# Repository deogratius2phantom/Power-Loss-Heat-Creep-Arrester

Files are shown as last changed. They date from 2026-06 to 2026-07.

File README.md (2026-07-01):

# Power Loss Heat Creep Arrester

A KiCad PCB design for a timer circuit that provides **24 V backup power to a 3D printer hotend fan** in the event of a power loss during printing. This prevents heat creep — the condition where residual heat travels up into the heatsink passage, causing filament to swell, clog, or jam.

---

## Overview

When a 3D printer loses power mid-print, the hotend heater turns off but residual heat remains in the heater block. Without the cooling fan running, this heat can creep up the cold zone, softening and swelling the filament inside the heatsink passage. The result is a jam that requires manual disassembly to clear.

This circuit detects the power loss event and uses a backup energy source (e.g. a capacitor bank or small battery) to keep the hotend fan spinning for a timed period — long enough for the heat to dissipate safely.

---

## Features

- Detects main power loss and triggers a timed backup fan drive
- Designed to supply 24 V to a standard 3D printer part-cooling or hotend fan
- Powered by a **Nokia BL-5C 3.7 V Li-ion battery** — widely available, compact, and plug-in replaceable
- Compact PCB footprint suitable for mounting inside a printer enclosure
- Fully open hardware (CC0 1.0 Universal licence)

---

## Board Preview

**Front (component side)**
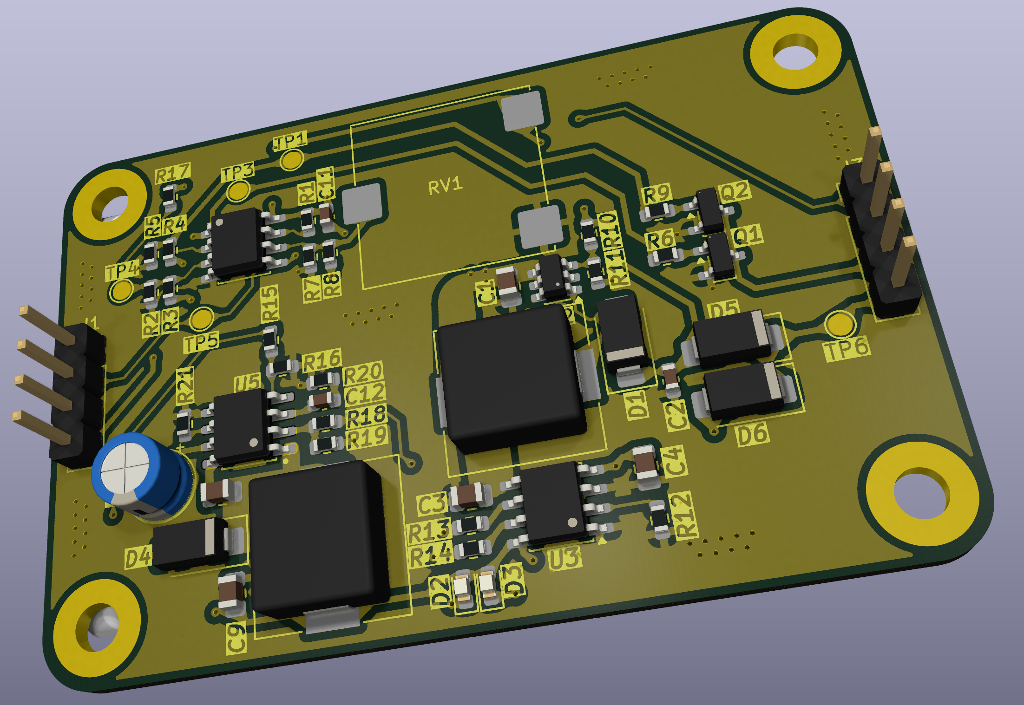
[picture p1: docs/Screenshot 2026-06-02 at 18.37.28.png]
Board Front


**Back — rev_1.0 silkscreen**
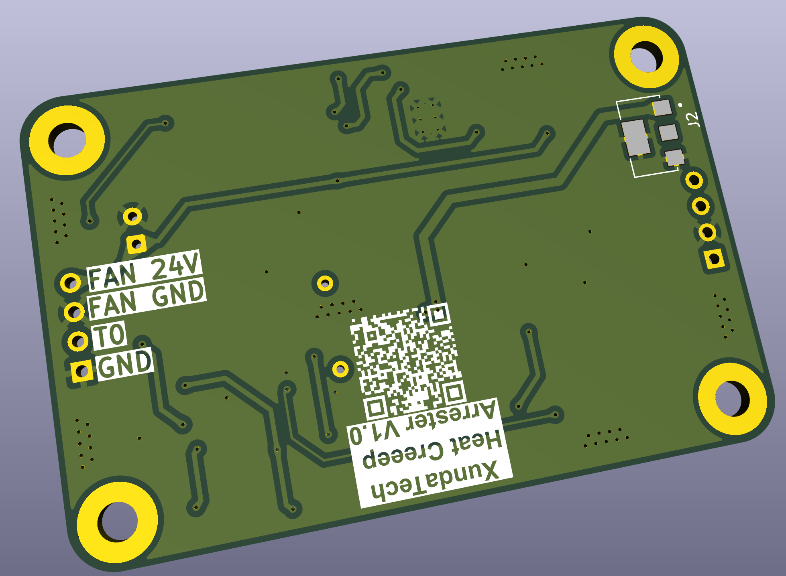
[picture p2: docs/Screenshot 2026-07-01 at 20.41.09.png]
Board Back rev_1.0


The back silkscreen includes:
- **XundaTech / Heat Creep Arrester V1.0** — product branding
- **QR code** — scan to open this GitHub repository directly from the physical board
- **Connector pinout labels** (`FAN 24V`, `FAN GND`, `TO`, `GND`) — printed next to J3 for field assembly without needing a datasheet

📄 Full schematic & layout documentation: [PowerLossHeatCreepArrester.pdf](docs/PowerLossHeatCreepArrester.pdf)

---

## Repository Structure

```
Power-Loss-Heat-Creep-Arrester/
├── PowerLossHeatCreepArrester_v1.0/                      # KiCad v1.0 project (main design)
│   ├── PowerLossHeatCreepArrester_v1.0.kicad_pro         # KiCad project file
│   ├── PowerLossHeatCreepArrester_v1.0.kicad_sch         # Schematic
│   ├── PowerLossHeatCreepArrester_v1.0.kicad_pcb         # PCB layout
│   ├── board_v1.step                                     # 3D board export (v1)
│   ├── board_v11.step                                    # 3D board export (v11)
│   ├── .step                                             # Additional 3D export
│   ├── fabrication-toolkit-options.json                  # KiCad fabrication toolkit config
│   ├── bom/                                              # Bill of Materials & assembly aids
│   │   └── manual_assembly_ibom.html                    # Interactive BOM for manual assembly
│   └── production/                                       # Ready-to-order production files
│       ├── PowerLossHeatCreepArrester_v1.0.zip           # Gerber bundle for PCB fab
│       ├── bom.csv                                       # Bill of Materials
│       ├── designators.csv                               # Component designators
│       ├── netlist.ipc                                   # IPC netlist
│       └── positions.csv                                 # Pick-and-place positions
├── libraries/
│   └── PowerLossHeatCreepArrester.kicad_sym              # Custom schematic symbols
├── footprints/
│   └── PowerLossHeatCreepArrester.pretty/                # Custom PCB footprints
├── fabrication/
│   ├── gerbers/                                          # Gerber files for PCB manufacture
│   └── bom/                                             # Bill of Materials exports
├── docs/                                                 # Documentation & board images
│   ├── PowerLossHeatCreepArrester.pdf                   # Full schematic & layout PDF
│   ├── Screenshot 2026-06-02 at 18.37.28.png            # Board front view
│   └── Screenshot 2026-06-02 at 18.37.43.png            # Board back view
├── Heat Creep Arrester.pdf                               # Project overview document
├── .gitignore
├── LICENSE
└── README.md
```

---

## Getting Started

### Prerequisites

- [KiCad 7 or later](https://www.kicad.org/download/) (the project files use the KiCad 6+ S-expression format)

### Opening the Project

1. Clone or download this repository.
2. Open KiCad and select **File → Open Project**.
3. Navigate to `PowerLossHeatCreepArrester_v1.0/` and open `PowerLossHeatCreepArrester_v1.0.kicad_pro`.
4. The schematic (`*.kicad_sch`) and PCB layout (`*.kicad_pcb`) will be available from the KiCad project manager.

### Generating Fabrication Files

### Interactive BOM (Manual Assembly)

Open the interactive BOM directly in your browser — no setup needed:

**🔗 [View Interactive BOM online](https://htmlpreview.github.io/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)**

Or open the file locally: `PowerLossHeatCreepArrester_v1.0/bom/manual_assembly_ibom.html`

It provides an interactive board view where you can click each component to highlight its placement — ideal for hand-soldering.

### Production Files

Ready-to-order files are in `PowerLossHeatCreepArrester_v1.0/production/`:

| File | Description |
|---|---|
| `PowerLossHeatCreepArrester_v1.0.zip` | Gerber bundle — upload directly to your PCB fab |
| `bom.csv` | Bill of Materials |
| `designators.csv` | Component designator mapping |
| `netlist.ipc` | IPC-D-356 netlist |
| `positions.csv` | Pick-and-place positions for SMT assembly |

To regenerate from source in KiCad PCB Editor (`pcbnew`):

1. Go to **File → Fabrication Outputs → Gerbers** → output to `fabrication/gerbers/`.
2. Generate the drill file via **File → Fabrication Outputs → Drill Files**.
3. Export the BOM via **File → Fabrication Outputs → BOM** → output to `fabrication/bom/`.

---

## Design Notes

| Parameter | Value |
|---|---|
| Supply voltage | 24 V |
| Target load | Hotend / part-cooling fan |
| Fan activation | Only when hotend > 50 °C (adjustable via RV1) |
| Temperature sensing | Independent thermistor circuit (U4) — separate from printer NTC |
| PCB layers | 2 |
| Board thickness | 1.6 mm |
| Solder mask clearance | 0.005 mm |

---

## Revision History

### rev_1.0 (current branch)

Key changes from initial commit:

- **Independent temperature monitoring (U4 added):** A dedicated temperature sensing IC with its own thermistor was added after determining it is not feasible to share the printer's NTC across both the printer control board and this backup supply board without a carefully designed 3.3 V interface. U4 provides a clean, isolated temperature signal to LM393 comparator 2.
- **Comparator voltage divider recalculated:** R15 `210k → 52.3k`, R16 `40.2k → 10k` — revised to correctly set the 24 V power-loss detection threshold.
- **Hysteresis / reference network updated:** R21 `200k → 100k`, plus two comparator reference resistors adjusted (`10k → 47k` and `10k → 910k`) to match the new divider ratios.
- **GND symbol rerouted and thermistor label repositioned** on the schematic for clarity.
- **Net label typo fixed:** `indipendent_3d printer fan control input` → `independent_3d printer fan control input`.
- **PCB layout updated:** U4 placed at (138.51, 88.06), net assignments updated to match schematic changes, solder mask clearance set to 0.005 mm.
- **Back silkscreen additions:**
  - Product branding: `XundaTech / Heat Creep Arrester V1.0`
  - QR code linking to this GitHub repository (centre-back)
  - Connector pinout labels beside J3: `FAN 24V`, `FAN GND`, `TO`, `GND`

---

## Documentation

Full project documentation is in the [**GitHub Wiki**](https://github.com/deogratius2phantom/Power-Loss-Heat-Creep-Arrester/wiki):

| Wiki Page | Contents |
|---|---|
| [Design Rationale](https://github.com/deogratius2phantom/Power-Loss-Heat-Creep-Arrester/wiki/Design-Rationale) | Why BL-5C, MT3608, TP4056, LM393 were chosen |
| [Circuit Theory](https://github.com/deogratius2phantom/Power-Loss-Heat-Creep-Arrester/wiki/Circuit-Theory) | How each circuit block works |
| [Bill of Materials & Sourcing](https://github.com/deogratius2phantom/Power-Loss-Heat-Creep-Arrester/wiki/Bill-of-Materials-and-Sourcing) | Full component list with supplier links |
| [Assembly Guide](https://github.com/deogratius2phantom/Power-Loss-Heat-Creep-Arrester/wiki/Assembly-Guide) | Step-by-step soldering instructions |
| [Testing & Calibration](https://github.com/deogratius2phantom/Power-Loss-Heat-Creep-Arrester/wiki/Testing-and-Calibration) | Verifying and tuning the circuit |
| [Troubleshooting](https://github.com/deogratius2phantom/Power-Loss-Heat-Creep-Arrester/wiki/Troubleshooting) | Common issues and fixes |
| [Version History](https://github.com/deogratius2phantom/Power-Loss-Heat-Creep-Arrester/wiki/Version-History) | Board revision log |

---

## Contributing

Contributions are welcome. See the [Contributing wiki page](https://github.com/deogratius2phantom/Power-Loss-Heat-Creep-Arrester/wiki/Contributing) for the full workflow. Please open an issue to discuss changes before submitting a pull request.

---

## Licence

This project is released into the public domain under the [CC0 1.0 Universal](LICENSE) licence. You are free to use, modify, and distribute this design without restriction.

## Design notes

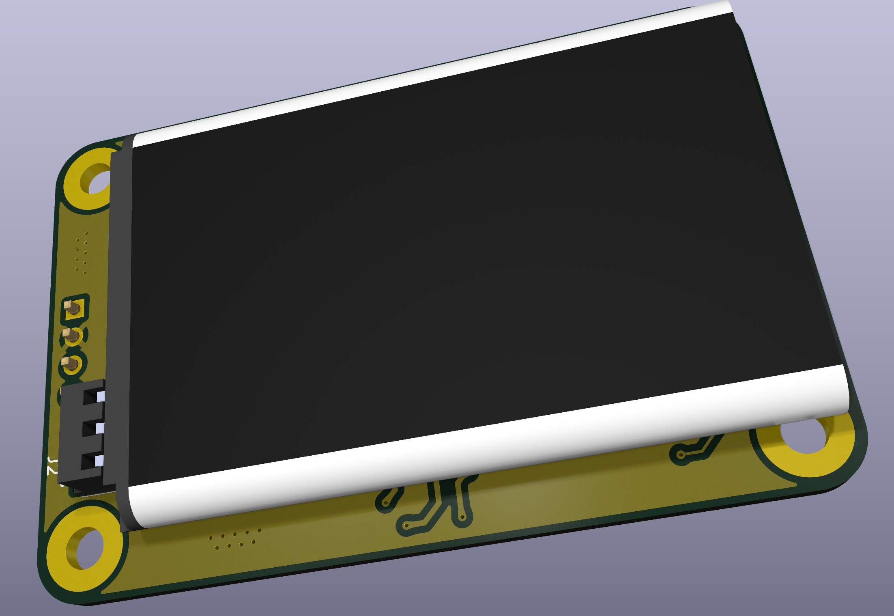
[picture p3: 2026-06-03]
docs/Screenshot 2026-06-02 at 18.37.43.png

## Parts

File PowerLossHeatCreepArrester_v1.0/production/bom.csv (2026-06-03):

Designator | Footprint | Quantity | Value | LCSC Part #
C1, C9 | 0805 | 2 | 22uF
C11, C2 | 0603 | 2 | 22uF
C12 | 0603 | 1 | 150pF
C3, C4 | 0805 | 2 | 10uF
C5 | 0805 | 1 | 1uF
C7 | CP_Radial_D5.0mm_P2.50mm | 1 | 100uF
D1, D4, D5, D6 | D_SMA | 4 | D
D2, D3 | 0603 | 2 | LED
J1 | PinHeader_1x04_P2.54mm_Vertical | 1 | Conn_01x04_Socket
J2 | AMPHENOL_BC3550Y0302A | 1 | BC3550Y0302A
J3 | PinHeader_1x04_P2.54mm_Vertical | 1 | Conn_01x04_Pin
L1, L2 | L_10.4x10.4_H4.8 | 2 | 22uH
Q1, Q2 | SOT-23 | 2 | BSS138
R1, R10, R11, R2, R3, R4, R7, R8 | 0603 | 8 | 10k
R12 | 0603 | 1 | 1.4k
R13, R14, R6, R9 | 0603 | 4 | 1k
R15 | 0603 | 1 | 210k
R16 | 0603 | 1 | 40.2k
R17 | 0603 | 1 | 1M
R18, R20 | 0603 | 2 | 100k
R19 | 0603 | 1 | 24.9k
R21 | 0603 | 1 | 200k
R5 | 0603 | 1 | 4.7k
RV1 | Potentiometer_ACP_CA14-VSMD_Vertical | 1 | 10K
TP1, TP3, TP4, TP5, TP6 | TestPoint_Pad_D1.5mm | 5 | TestPoint_Alt
U1 | SOIC-8_3.9x4.9mm_P1.27mm | 1 | LM393
U2 | SOT-23-6 | 1 | MT3608
U3 | SOIC-8-1EP_3.9x4.9mm_P1.27mm_EP2.41x3.3mm_ThermalVias | 1 | TP4056-42-ESOP8
U5 | SOIC127P600X170-9N | 1 | MP1584EN

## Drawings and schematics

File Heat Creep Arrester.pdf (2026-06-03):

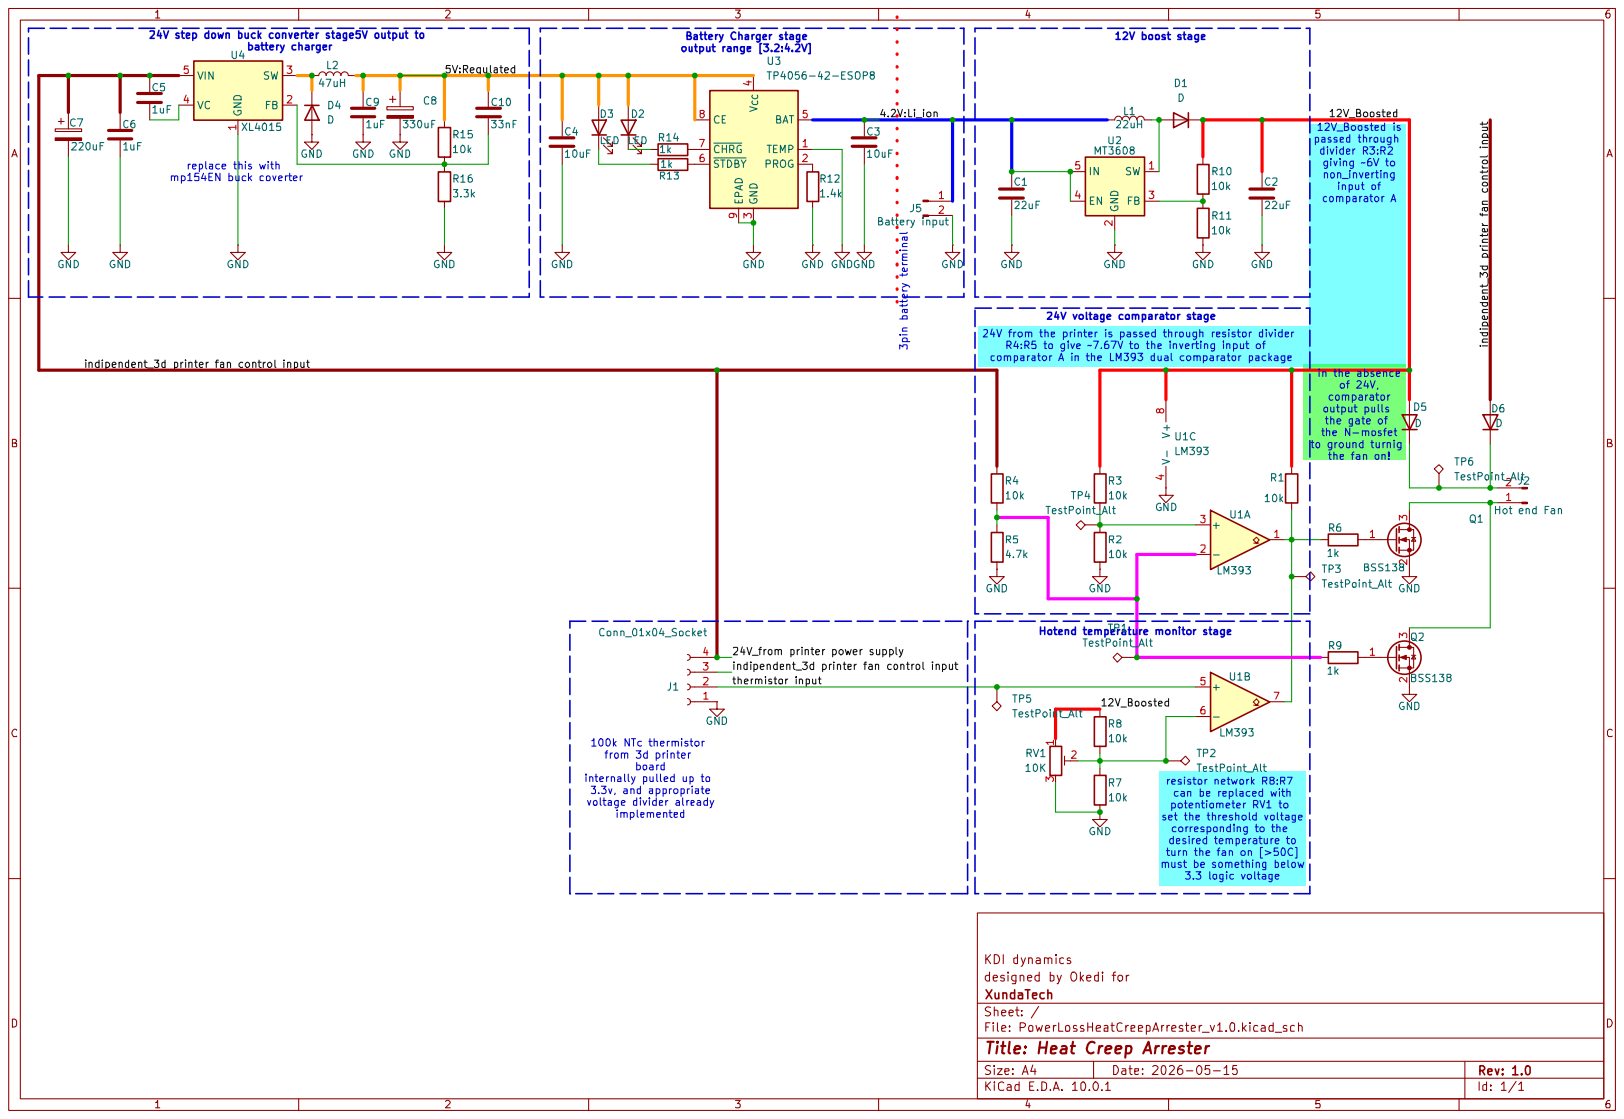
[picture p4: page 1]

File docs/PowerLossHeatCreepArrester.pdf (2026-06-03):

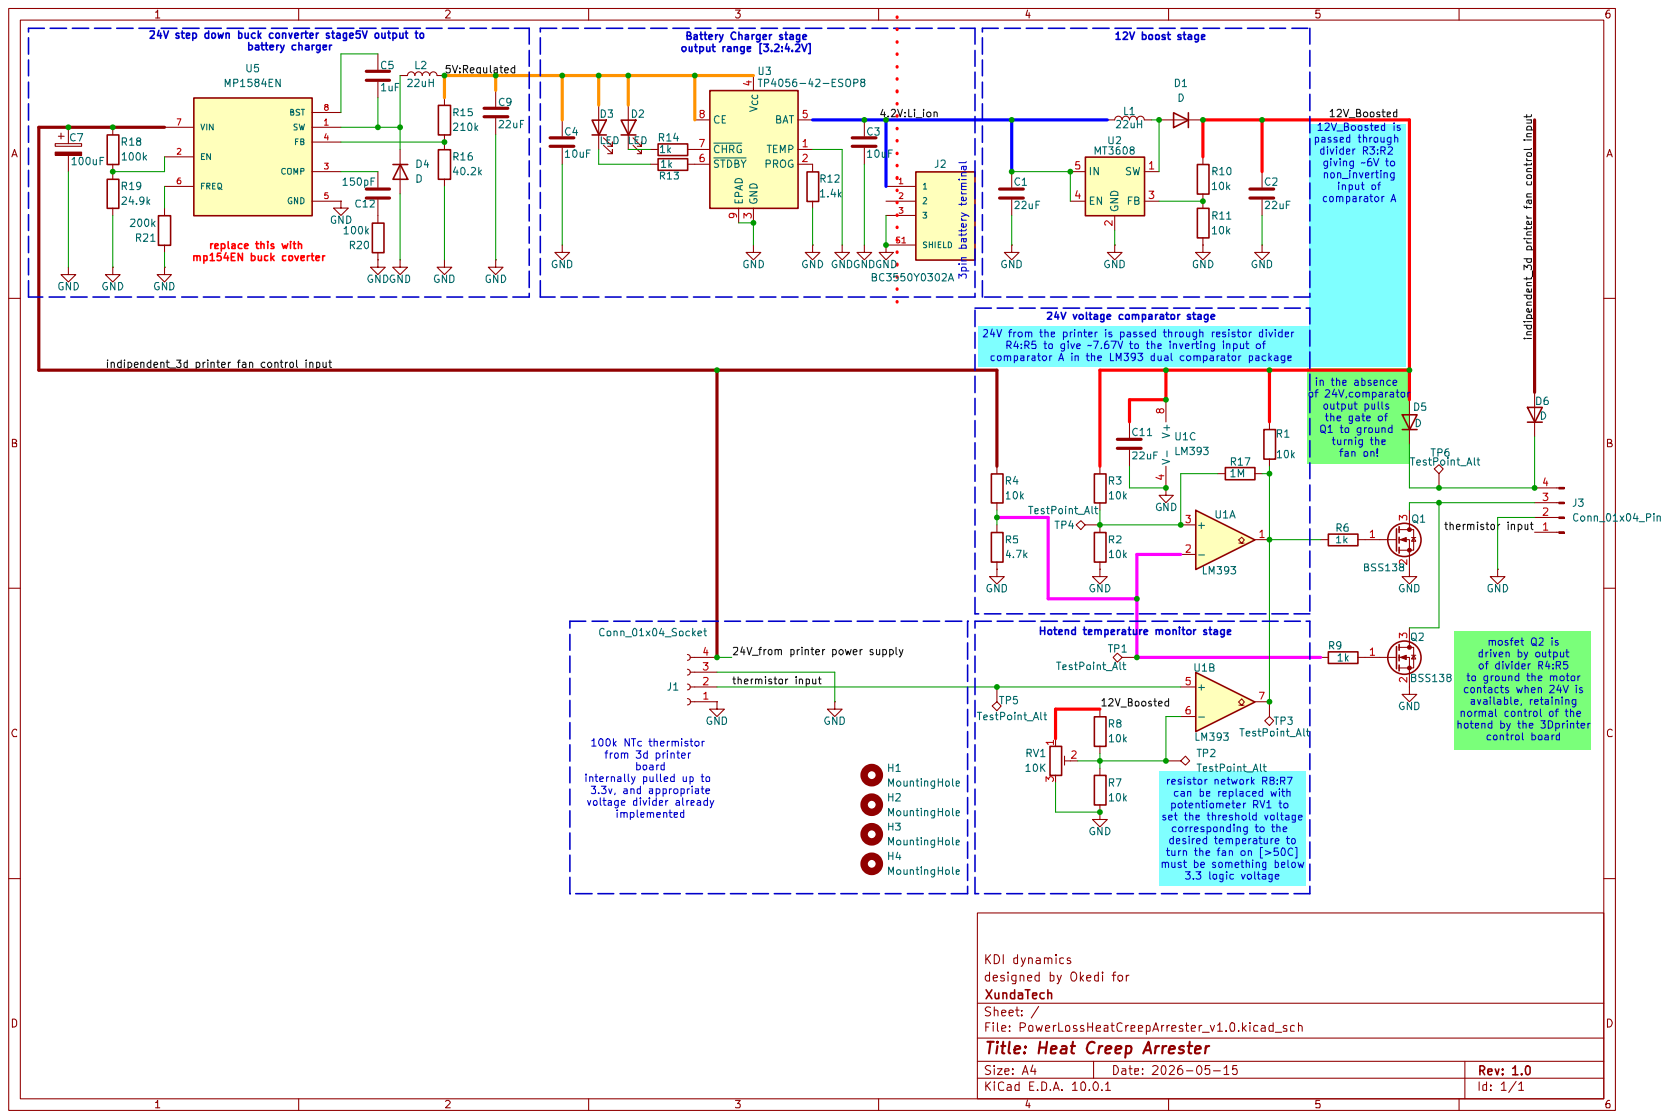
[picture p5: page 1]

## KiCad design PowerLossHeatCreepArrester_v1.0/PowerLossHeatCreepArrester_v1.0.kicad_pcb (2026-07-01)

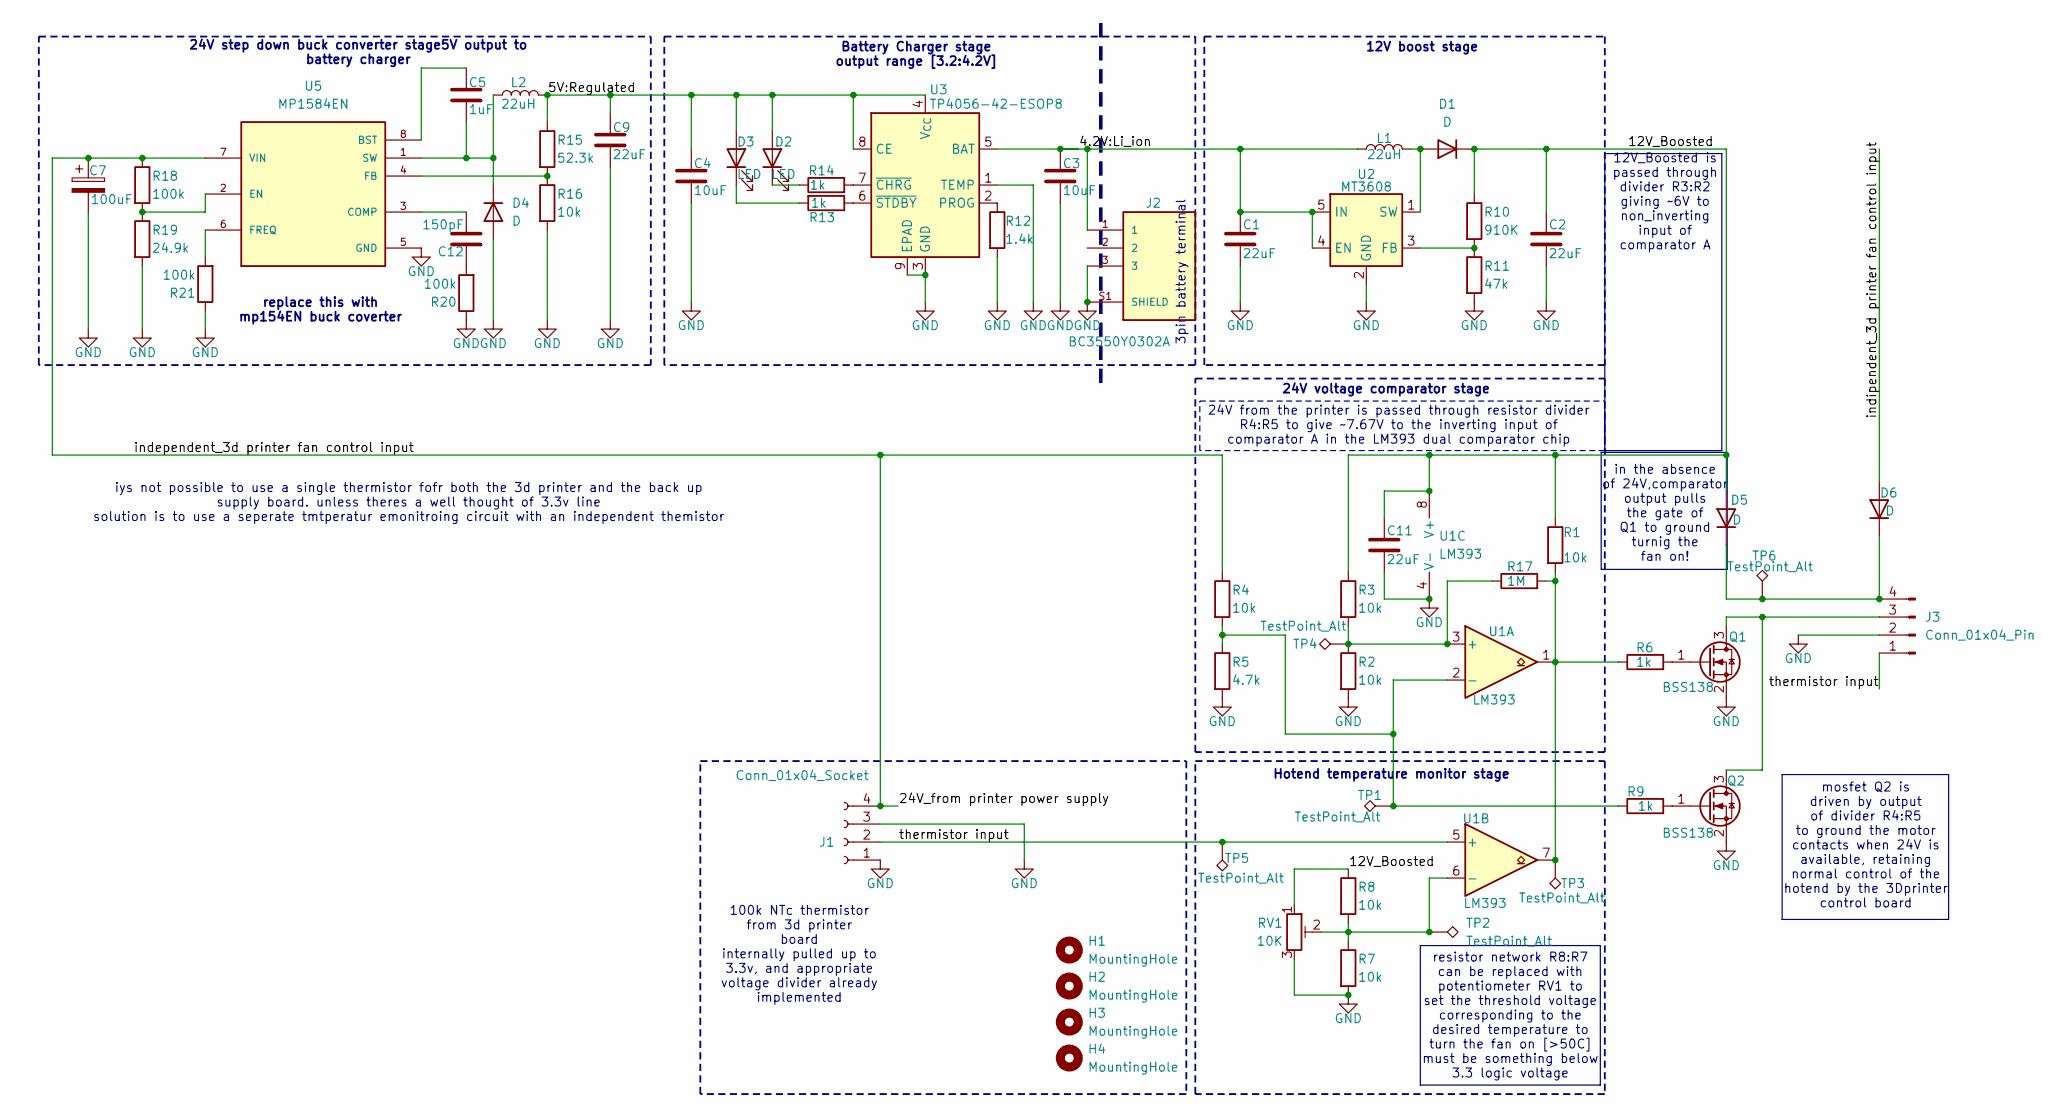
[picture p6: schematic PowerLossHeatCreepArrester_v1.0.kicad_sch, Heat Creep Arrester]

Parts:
C1, C9: 22uF; C_0805_2012Metric
C2, C11: 22uF; C_0603_1608Metric
C3, C4: 10uF; C_0805_2012Metric
C5: 1uF; C_0805_2012Metric
C7: 100uF; CP_Radial_D5.0mm_P2.50mm
C12: 150pF; C_0603_1608Metric
D1, D4, D5, D6: D; D_SMA
D2, D3: LED; LED_0603_1608Metric
H1, H2, H3, H4: MountingHole; MountingHole_3.2mm_M3_Pad
J1: Conn_01x04_Socket; PinHeader_1x04_P2.54mm_Vertical
J2: BC3550Y0302A; AMPHENOL_BC3550Y0302A; PARTREV 4
J3: Conn_01x04_Pin; PinHeader_1x04_P2.54mm_Vertical
L1, L2: 22uH; L_10.4x10.4_H4.8
Q1, Q2: BSS138; SOT-23
R1, R2, R3, R4, R7, R8, R16: 10k; R_0603_1608Metric
R5: 4.7k; R_0603_1608Metric
R6, R9, R13, R14: 1k; R_0603_1608Metric
R10: 910K; R_0603_1608Metric
R11: 47k; R_0603_1608Metric
R12: 1.4k; R_0603_1608Metric
R15: 52.3k; R_0603_1608Metric
R17: 1M; R_0603_1608Metric
R18, R20, R21: 100k; R_0603_1608Metric
R19: 24.9k; R_0603_1608Metric
RV1: 10K; Potentiometer_ACP_CA14-VSMD_Vertical
TP1, TP2, TP3, TP4, TP5, TP6: TestPoint_Alt; TestPoint_Pad_D1.5mm
U1: LM393; SOIC-8_3.9x4.9mm_P1.27mm
U2: MT3608; SOT-23-6
U3: TP4056-42-ESOP8; SOIC-8-1EP_3.9x4.9mm_P1.27mm_EP2.41x3.3mm_ThermalVias
U5: MP1584EN; SOIC127P600X170-9N

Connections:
/4.2V:Li_ion: C1.1, C3.1, J2.1, L1.1, U2.4 (EN), U2.5 (IN), U3.5 (BAT)
/5V:Regulated: C4.1, C9.1, D2.2 (A), D3.2 (A), L2.2, R15.1, U3.4 (V_{CC}), U3.8 (CE)
/12V_Boosted: C2.1, C11.1, D1.1 (K), D5.2 (A), R1.1, R3.1, R8.1, R10.1, RV1.1, U1.8 (V+)
/thermistor input: J1.2, J3.1, TP5.1 (1_1), U1.5 (+)
GND: C1.2, C2.2, C3.2, C4.2, C7.2, C9.2, C11.2, D4.2 (A), J1.1, J1.3, J2.3, J2.S1 (SHIELD), J3.2, Q1.2 (S), Q2.2 (S), R2.2, R5.2, R7.2, R11.2, R12.2, R16.2, R19.2, R20.1, R21.1, RV1.3, U1.4 (V-), U2.2 (GND), U3.1 (TEMP), U3.3 (GND), U3.9 (EPAD), U5.5 (GND), U5.9 (GND)
unnamed: C12.1, R20.2
unnamed: D1.2 (A), L1.2, U2.1 (SW)
unnamed: D2.1 (K), R14.1
unnamed: D3.1 (K), R13.2
unnamed: C5.2, D4.1 (K), L2.1, U5.1 (SW)
unnamed: D5.1 (K), D6.1 (K), J3.4, TP6.1 (1_1)
unnamed: J3.3, Q1.3 (D), Q2.3 (D)
unnamed: Q1.1 (G), R6.2
unnamed: Q2.1 (G), R9.2
unnamed: R1.2, R6.1, R17.2, TP3.1 (1_1), U1.1, U1.7
unnamed: R2.1, R3.2, R17.1, TP4.1 (1_1), U1.3 (+)
unnamed: R4.2, R5.1, R9.1, TP1.1 (1_1), U1.2 (-)
unnamed: R7.1, R8.2, RV1.2, TP2.1, U1.6 (-)
unnamed: R10.2, R11.1, U2.3 (FB)
unnamed: R12.1, U3.2 (PROG)
unnamed: R14.2, U3.7 (~CHRG)
unnamed: R13.1, U3.6 (~STDBY)
unnamed: C5.1, U5.8 (BST)
unnamed: C12.2, U5.3 (COMP)
unnamed: R18.2, R19.1, U5.2 (EN)
unnamed: R15.2, R16.1, U5.4 (FB)
unnamed: R21.2, U5.6 (FREQ)

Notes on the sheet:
24V from the printer is passed through resistor divider R4:R5 to give ~7.67V to the inverting input of comparator A in the LM393 dual comparator chip
24V voltage comparator stage
Hotend temperature monitor stage
iys not possible to use a single thermistor fofr both the 3d printer and the back up supply board. unless theres a well thought of 3.3v line solution is to use a seperate tmtperatur emonitroing circuit with an independent themistor
3pin battery terminal
Battery Charger stage output range [3.2:4.2V]
in the absence of 24V,comparator output pulls the gate of Q1 to ground turnig the fan on!
100k NTc thermistor from 3d printer board internally pulled up to 3.3v, and appropriate voltage divider already implemented
12V boost stage
resistor network R8:R7 can be replaced with potentiometer RV1 to set the threshold voltage corresponding to the desired temperature to turn the fan on [>50C] must be something below 3.3 logic voltage
replace this with mp154EN buck coverter
12V_Boosted is passed through divider R3:R2 giving ~6V to non_inverting input of comparator A
24V step down buck converter stage5V output to battery charger
mosfet Q2 is driven by output of divider R4:R5 to ground the motor contacts when 24V is available, retaining normal control of the hotend by the 3Dprinter control board

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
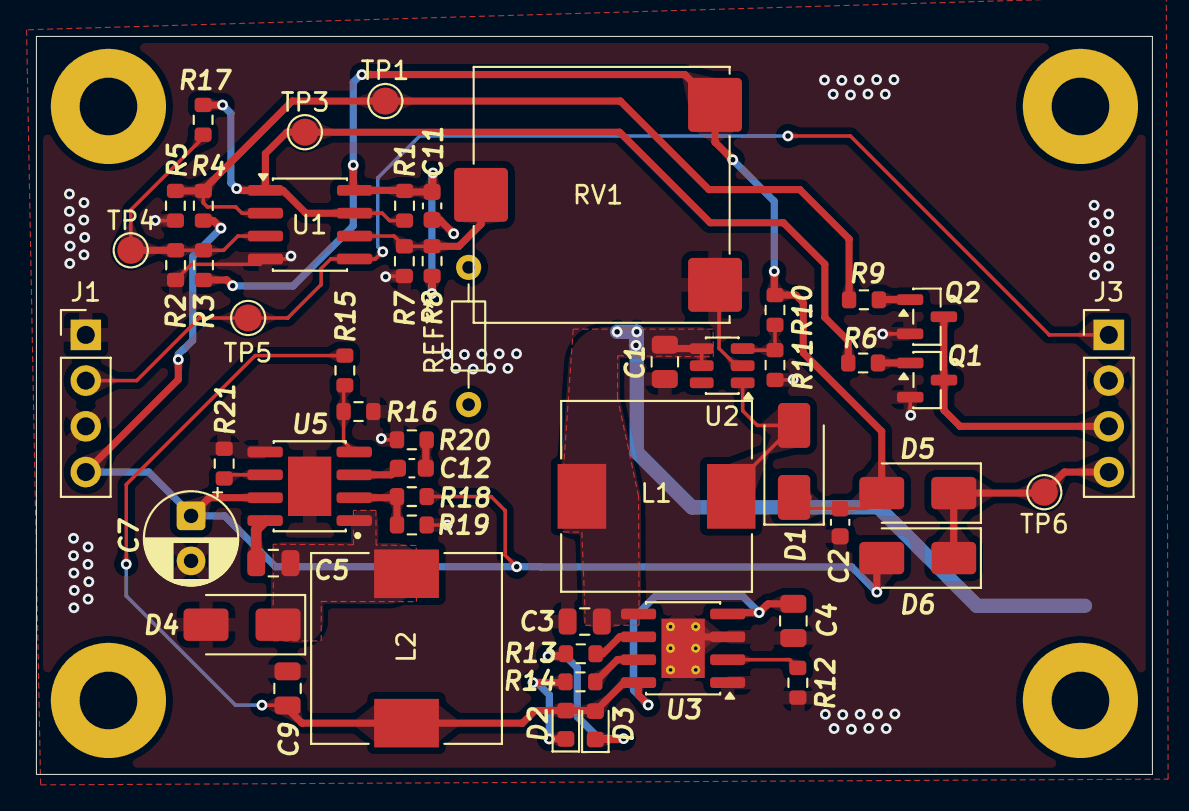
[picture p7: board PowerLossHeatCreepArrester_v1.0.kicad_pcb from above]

Board: 2 copper layers, 62.0 x 41.0 mm, 57 parts (1 on the bottom side), 28 nets.

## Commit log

2026-03-14 Configure KiCad PCB project structure with appropriate README
    [PowerLossHeatCreepArrester.kicad_pcb, PowerLossHeatCreepArrester.kicad_sch]
2026-06-02 Add KiCad v1.0 project files (PowerLossHeatCreepArrester_v1.0)
    - Add PCB layout (.kicad_pcb)
    - Add schematic (.kicad_sch)
    - Add project file (.kicad_pro)
    - Add 3D STEP exports (.step, board_v1.step, board_v11.step)
    - Update .gitignore to exclude .history/ directories
    [PowerLossHeatCreepArrester_v1.0.kicad_pcb, PowerLossHeatCreepArrester_v1.0.kicad_sch]
2026-06-02 Remove root KiCad files, consolidate project in PowerLossHeatCreepArrester_v1.0/
    The v1.0 subfolder contains the definitive board design with
    complete schematics and PCB layout.
    [PowerLossHeatCreepArrester.kicad_pcb, PowerLossHeatCreepArrester.kicad_sch]
2026-06-03 updated readme file with pictures
    [PowerLossHeatCreepArrester_v1.0.kicad_sch, bom.csv, designators.csv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]
2026-06-03 Update README: add PCB previews from docs/, reflect actual repo structure
    - Link to docs/PowerLossHeatCreepArrester.pdf in Board Preview section
    - Update Repository Structure tree to match tracked files (production/ folder,
    fabrication-toolkit-options.json, .step, Heat Creep Arrester.pdf, docs contents)
    - Expand Generating Fabrication Files section with production/ file table
2026-06-03 Add interactive BOM for manual assembly and update README
    - Track PowerLossHeatCreepArrester_v1.0/bom/manual_assembly_ibom.html
    - Add bom/ to repo structure tree in README
    - Add Interactive BOM section in Getting Started
2026-06-03 README: add BL-5C battery feature, add online interactive BOM link
    - Mention Nokia BL-5C 3.7V Li-ion battery in Features section
    - Add htmlpreview.github.io link so contributors can view the
    interactive BOM directly in the browser without cloning the repo
2026-06-03 README: correct Design Notes — fan activates above 50°C, not RC timer
2026-07-01 rev_1.0: independent temperature sensing, comparator divider redesign
    Hardware changes:
    - Add U4: independent temperature monitoring IC with dedicated thermistor.
    Sharing the printer's NTC directly with this board is not feasible without
    a 3.3 V interface solution; U4 provides an isolated temperature signal to
    LM393 comparator 2 for the > 50 °C fan activation threshold.
    Schematic (kicad_sch):
    - Recalculate comparator 1 (power-loss) voltage divider:
    R15: 210k → 52.3k
    R16: 40.2k → 10k
    - Update hysteresis / reference network:
    R21: 200k → 100k
    Comparator reference resistors: 10k → 47k and 10k → 910k
    - Reroute GND symbol and reposition thermistor net label for cl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
    [PowerLossHeatCreepArrester_v1.0.kicad_pcb, PowerLossHeatCreepArrester_v1.0.kicad_sch]
2026-07-01 rev_1.0: add back silkscreen screenshot, update Board Preview and Revision History
    - Add docs/Screenshot 2026-07-01 at 20.41.09.png: 3D render of board back
    showing XundaTech branding, QR code linking to repo, J3 pinout labels
    - README Board Preview: replace placeholder back image with rev_1.0 silk
    screenshot and describe silkscreen contents
    - README Revision History: add back silkscreen bullet points
